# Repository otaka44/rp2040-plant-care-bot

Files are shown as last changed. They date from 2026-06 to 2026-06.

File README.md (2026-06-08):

# 土壌水分センシングロボット（弱いロボット）

RP2040-Zeroを用いた土壌水分センシングロボットのリポジトリです。  
このロボットは、土壌の水分量に応じて表情を変化させることで、人間に対して自然な「助け合い」の動機付けを生み出す「弱いロボット」として設計されています。水分センサーの読み取り、状態に応じた表情制御、およびハードウェア構成に関するソースコードを管理しています。

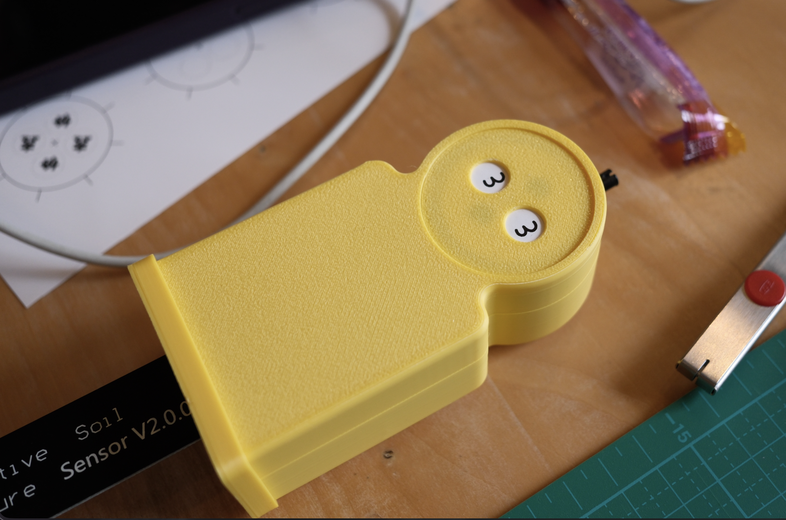
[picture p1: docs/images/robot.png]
完成品


photo by [otaka44](https://github.com/otaka44)

---

## パーツリスト

| パーツ | 型番 | 入手先 | 単価 |
|---|---|---|---|
| マイコン | RP2040-Zero | - | - |
| 静電容量式土壌水分センサー | ノーブランド | - | - |
| サーボモータ | SG90S | [秋月電子 108761](https://akizukidenshi.com/catalog/g/g108761/) | ¥650 |
| ロードスイッチ | TCK108AF | [秋月電子 116073](https://akizukidenshi.com/catalog/g/g116073/) | ¥150 |
| セラミックコンデンサ | 100μF | - | - |
| (*オプション) 圧電スピーカ | PKM13EPYH4000-A0 | [秋月電子 104118](https://akizukidenshi.com/catalog/g/g104118/) | ¥30 |

---

## 回路図

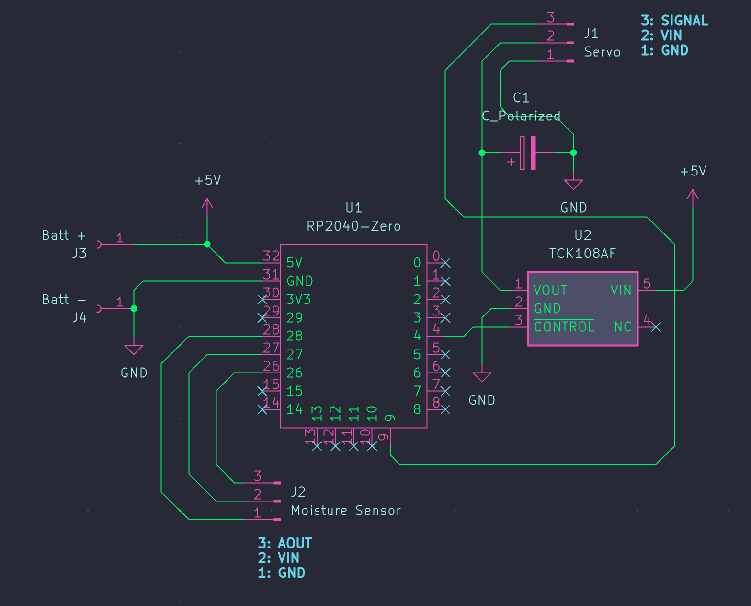
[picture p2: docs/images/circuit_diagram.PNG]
回路図


designed by [Atsuyuki](https://www.instagram.com/aaa_tu)

### 回路の概要

バッテリーから電源を供給し、RP2040-Zeroで水分センサーの値を読み取り、TCK108AF（ロードスイッチ）を介してサーボモーターの電源を制御する構成

| コンポーネント | ピン名称 | 接続先 | 備考 |
| --- | --- | --- | --- |
| **バッテリー (J3)** | 1 (+V) | RP2040-Zero (32ピン: 5V) | 電源供給 |
| **バッテリー (J4)** | 1 (GND) | RP2040-Zero (31ピン: GND) | グランド |
| **RP2040-Zero** | 28ピン | Moisture Sensor (3ピン) | - |
| **RP2040-Zero** | 27ピン | Moisture Sensor (2ピン) | - |
| **RP2040-Zero** | 26ピン | Moisture Sensor (1ピン) | - |
| **RP2040-Zero** | 4ピン | TCK108AF (3ピン: CONTROL) | 電源ON/OFF制御 |
| **TCK108AF** | 1ピン (VOUT) | Servo (1ピン) | サーボ電源出力 |
| **TCK108AF** | 2ピン (GND) | RP2040-Zero (31ピン: GND) | グランド|
| **TCK108AF** | 5ピン (VIN) | +5V (バッテリー側) | 電源供給 |
| **Servo** | 2ピン | RP2040-Zero (9ピン: PWM) | 信号線 |
| **Servo** | 3ピン | RP2040-Zero (31ピン: GND) | グランド |
| **C1 (コンデンサ)** | + | TCK108AF (1ピン: VOUT) | 平滑用 |
| **C1 (コンデンサ)** | - | GND | - |

```mermaid
graph TD
    %% 電源系
    Batt_Plus[Batt + J3] -- +5V --> PowerRail[+5V Rail]
    Batt_Minus[Batt - J4] -- GND --> GNDRail[GND Rail]

    %% マイコン
    subgraph RP2040-Zero [U1: RP2040-Zero]
        P32[Pin 32: 5V]
        P31[Pin 31: GND]
        P28[Pin 28]
        P27[Pin 27]
        P26[Pin 26]
        P9[Pin 4: CONTROL]
        P4[Pin 9: Signal]
    end

    %% スイッチ
    subgraph TCK108AF [U2: TCK108AF]
        U2_1[1: VOUT]
        U2_2[2: GND]
        U2_3[3: CONTROL]
        U2_5[5: VIN]
    end

    %% 周辺機器
    subgraph Moisture_Sensor [J2: Moisture Sensor]
        MS3[3]
        MS2[2]
        MS1[1]
    end

    subgraph Servo [J1: Servo]
        SV1[1: VCC]
        SV2[2: Signal]
        SV3[3: GND]
    end

    subgraph Capacitor [C1]
        C_Pos[+]
        C_Neg[-]
    end

    %% 結線
    PowerRail --> P32
    PowerRail --> U2_5
    GNDRail --> P31
    GNDRail --> U2_2
    GNDRail --> SV3
    GNDRail --> C_Neg

    P28 --- MS3
    P27 --- MS2
    P26 --- MS1

    P9 --> SV2
    U2_1 --> SV1
    U2_1 --> C_Pos
    P4 --> U2_3

    %% スタイル定義
    classDef power fill:#f9f,stroke:#333,stroke-width:2px;
    class PowerRail,GNDRail power;
```

* **RP2040-Zero**: システムの中枢です。
* **水分センサー (Moisture Sensor)**: 26, 27, 28ピンを使用してデータを取得しています。
* **サーボモーター制御**:
* TCK108AFはロードスイッチ（パワーゲート）です。RP2040-Zeroの4ピン（CONTROL）から信号を送ることで、サーボモーターへの電源供給をオンオフする仕組みになっています。サーボモーターのPWM信号はRP2040-Zeroの9ピンから送ります。
* これにより、必要な時だけサーボを動かす省電力設計が可能です。
* **電源**: J3/J4から入力された5VがそのままRP2040-Zeroに供給され、そこから分岐してTCK108AFのVIN（5ピン）に入っています。

---

## ディレクトリ構成

```text
rp2040-zero/
├── README.md
├── docs/
│   └── spec.md
└── src/
    ├── code.py
    └── lib/
        ├── __init__.py
        ├── load_switch.py
        ├── moisture_sensor.py
        ├── piezo_speaker.py
        └── servo_controller.py
```

### ファイルの役割

| パス | 役割 |
| --- | --- |
| `docs/spec.md` | 実装要件の整理 |
| `src/code.py` | Thonny から実行する CircuitPython のメインスクリプト |
| `src/lib/load_switch.py` | TCK108AF の制御ライブラリ |
| `src/lib/moisture_sensor.py` | 水分センサーのアナログ値取得とキャリブレーション |
| `src/lib/servo_controller.py` | PWM によるサーボ角度制御 |
| `src/lib/piezo_speaker.py` | 圧電スピーカーの効果音再生 |

---

## ライブラリ説明

### `load_switch.py`

ロードスイッチ TCK108AF の CONTROL ピンをデジタル出力で制御します。サーボを動かす瞬間だけ電源を供給し、待機中はオフにするために使います。

* `LoadSwitch(pin, active_high=True, initial_on=False)`
* `on()` で電源オン
* `off()` で電源オフ
* `set(on)` で任意状態に設定

### `servo_controller.py`

50Hz PWM を使ってサーボ角度を制御します。角度は 0-180 度の範囲で扱い、内部でパルス幅に変換します。

* `ServoController(pin, min_angle=0, max_angle=180, min_pulse_us=500, max_pulse_us=2400)`
* `set_angle(angle, settle_sec=0.25)` で指定角度へ移動
* `off()` で PWM 出力を停止

### `moisture_sensor.py`

水分センサーのアナログ値を読み取り、電圧値と水分率に変換します。乾燥時と湿潤時の ADC 値を持たせているため、後からキャリブレーション可能です。

* `MoistureSensor(analog_pin, dry_raw=52000, wet_raw=20000, vref=3.3)`
* `read_raw()` で ADC 生値を取得
* `read_voltage()` で電圧値を取得
* `read_percent()` で 0-100% に正規化した水分率を取得
* `set_calibration(dry_raw=None, wet_raw=None)` で校正値を更新

### `piezo_speaker.py`

圧電スピーカーが実装された場合に、状態変化に応じた効果音を鳴らします。未搭載の場合は `src/code.py` で無効化できます。

* `PiezoSpeaker(pin)`
* `tone(frequency_hz, duration_sec=0.1, duty_cycle=32768)`
* `play_dry_effect()`
* `play_wet_effect()`
* `play_humid_effect()`

---

## メインロジック仕様

`src/code.py` は Thonny 上でそのまま実行するメインスクリプトです。一定時間ごとにセンサー値を読み取り、土壌状態を判定し、状態が変わった時だけサーボを動かします。

### 制御フロー

1. 各ライブラリを初期化する
2. 水分センサーの値を一定間隔で読む
3. 水分率から `dry` / `moist` / `wet` を判定する
4. 状態が前回から変化していたらロードスイッチをオンにする
5. サーボを状態に対応した角度へ動かす
6. サーボ移動後にロードスイッチをオフにする
7. スピーカーが有効なら状態に応じた音を鳴らす
8. 次の読み取りまで待機する

### 主な設定変数

| 変数名 | 初期値 | 説明 |
| --- | --- | --- |
| `SERVO_SIGNAL_PIN` | `board.GP9` | サーボ信号線の接続先 |
| `LOAD_SWITCH_PIN` | `board.GP4` | TCK108AF の CONTROL ピン |
| `MOISTURE_ANALOG_PIN` | `board.GP26` | 水分センサーのアナログ入力 |
| `SPEAKER_PIN` | `None` | 圧電スピーカーのピン。未実装時は `None` |
| `DRY_RAW` | `52000` | 乾燥状態として扱う ADC 生値 |
| `WET_RAW` | `20000` | 湿潤状態として扱う ADC 生値 |
| `DRY_THRESHOLD` | `35.0` | 乾燥判定の閾値 [%] |
| `WET_THRESHOLD` | `70.0` | 湿潤判定の閾値 [%] |
| `ANGLE_DRY` | `150` | 乾燥時のサーボ角度 |
| `ANGLE_MOIST` | `90` | 中間状態のサーボ角度 |
| `ANGLE_WET` | `30` | 湿潤時のサーボ角度 |
| `READ_INTERVAL_SEC` | `5.0` | センサー読み取り周期 [秒] |

### 状態判定

* 水分率 `< DRY_THRESHOLD` の場合は `dry`
* 水分率 `>= WET_THRESHOLD` の場合は `wet`
* それ以外は `moist`

### サーボ角度対応

| 状態 | 角度 |
| --- | --- |
| `dry` | `ANGLE_DRY` |
| `moist` | `ANGLE_MOIST` |
| `wet` | `ANGLE_WET` |

### Thonny での運用

* `src/code.py` を `CIRCUITPY/code.py` として配置して実行します
* シェルに `raw=... voltage=... moisture=... state=...` のログが表示されます
* 停止時は Thonny の Shell から `Ctrl+C` を送ります
* キャリブレーション時は `DRY_RAW`, `WET_RAW`, `DRY_THRESHOLD`, `WET_THRESHOLD` を調整します

## 謝辞

本プロジェクトは、watage youth studio「まちの実験室」第3回プログラム —— 「土からはじまる、神田のまちの育て方」にて実施したワークショップ[『土の声をきく、弱いロボットをつくろう』](https://machinojikkennshitsu.peatix.com/view)より生まれました。

本プロジェクトの推進にあたり、ロボットの設計およびデザインは [Atsuyuki](https://www.instagram.com/aaa_tu) 氏を中心とした[otaka44](https://github.com/otaka44)含む関係者一同が担いました。引き続き、拡張パーツの製作ならびに機能拡張に関わるソフトウェアの実装・管理を [otaka44](https://github.com/otaka44)が担当しています。

去る6月7日（日）に開催された本イベントには、多くの方々にご関心をお寄せいただき、無事に実施することができました。会場を提供いただいた watage —Hub for community cultivation— をはじめ、本プロジェクトにご協力いただいたすべての関係者の皆様に、心より御礼申し上げます。

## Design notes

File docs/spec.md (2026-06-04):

## 仕様

- 各パーツを制御するコードを`src/lib/`配下に作成する
- 各パーツリストと回路図は [こちらを参照](../README.md)
- `src/code.py`から各ライブラリを読み込む
- ライブラリは、以下の制御用スクリプトである。
    1. サーボ制御
    2. ロードスイッチ制御
    3. 水分センサーからのアナログ値取得
    4. (オプション)圧電スピーカー制御
- メインロジックは、ある一定時間ごとに土壌水分センサーの値を読み込み、センサーの値によってサーボ角を変化させる。土壌水分センサーの値から土壌が「乾いているか」「湿っているか」の判定閾値は後からキャリブレーションできるようにする。サーボのオンオフはロードスイッチで制御する。オプションとして、後から圧電スピーカーを追加すると、土壌水分センサーの値によるサーボ角変化と合わせて効果音を出すようにすることができる。
- 開発環境は`Thonny`、言語はCircuitPythonを利用する。

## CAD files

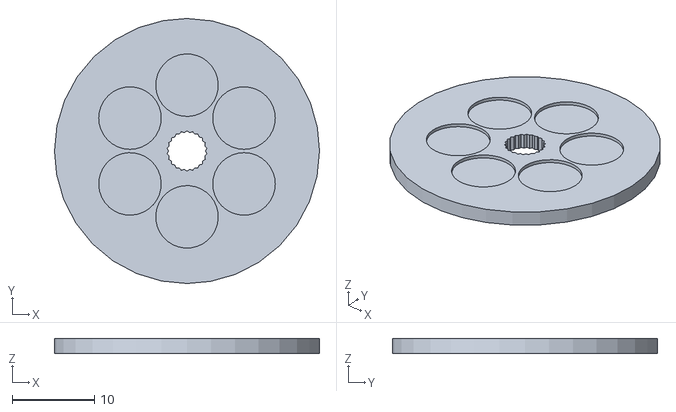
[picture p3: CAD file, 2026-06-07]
case/60deg_face_plate.stl
32.2 x 32.2 x 1.80

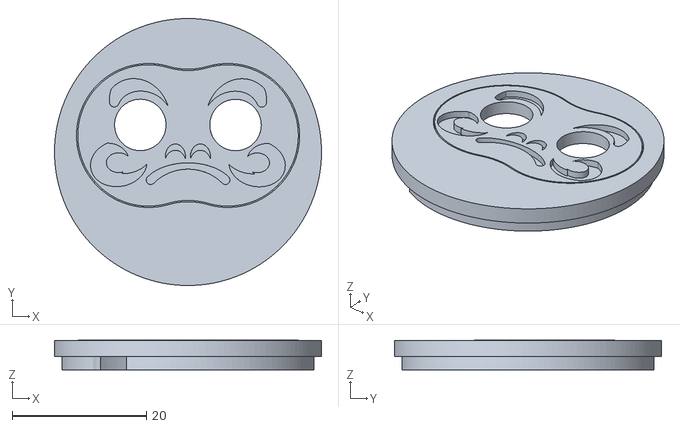
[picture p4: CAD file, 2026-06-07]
case/daruma_fase.stl
39.8 x 39.8 x 4.42

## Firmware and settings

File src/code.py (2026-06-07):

import time

import board

from lib.load_switch import LoadSwitch
from lib.moisture_sensor import MoistureSensor
from lib.piezo_speaker import PiezoSpeaker
from lib.servo_controller import ServoController


# Hardware pin mapping (RP2040-Zero + schematic in README)
SERVO_SIGNAL_PIN = board.GP9
LOAD_SWITCH_PIN = board.GP4
MOISTURE_ANALOG_PIN = board.GP26
MOISTURE_VCC_PIN = board.GP27
MOISTURE_GND_PIN = board.GP28

# Set to None if speaker is not mounted yet.
SPEAKER_PIN = None

# Moisture calibration (adjust later from measured values)
DRY_RAW = 51788
WET_RAW = 25795

# Decision thresholds for soil condition [percent]
DRY_THRESHOLD = 35.0
WET_THRESHOLD = 70.0

# Servo target angles by soil state
ANGLE_DRY = 90
ANGLE_MOIST = 30
ANGLE_WET = 150

# Main loop interval [seconds]
READ_INTERVAL_SEC = 5.0

# Multi-sample stabilization for noisy moisture readings.
MOISTURE_SAMPLE_COUNT = 5
MOISTURE_SAMPLE_INTERVAL_SEC = 0.02


def classify_moisture(percent):
    if percent < DRY_THRESHOLD:
        return "dry"
    if percent >= WET_THRESHOLD:
        return "wet"
    return "moist"


def angle_for_state(state):
    if state == "dry":
        return ANGLE_DRY
    if state == "wet":
        return ANGLE_WET
    return ANGLE_MOIST


def play_effect(speaker, state):
    if speaker is None:
        return
    if state == "dry":
        speaker.play_dry_effect()
    elif state == "wet":
        speaker.play_wet_effect()
    else:
        speaker.play_humid_effect()


def main():
    load_switch = LoadSwitch(LOAD_SWITCH_PIN, active_high=True, initial_on=False)
    servo = ServoController(SERVO_SIGNAL_PIN)
    sensor = MoistureSensor(
        MOISTURE_ANALOG_PIN,
        dry_raw=DRY_RAW,
        wet_raw=WET_RAW,
        vcc_pin=MOISTURE_VCC_PIN,
        gnd_pin=MOISTURE_GND_PIN,
    )
    speaker = PiezoSpeaker(SPEAKER_PIN) if SPEAKER_PIN is not None else None

    previous_state = None
    print("Soil robot start")
    print("Press Ctrl+C in Thonny shell to stop")

    try:
        while True:
            raw = sensor.read_raw_stabilized(
                sample_count=MOISTURE_SAMPLE_COUNT,
                interval_sec=MOISTURE_SAMPLE_INTERVAL_SEC,
            )
            voltage = sensor.raw_to_voltage(raw)
            percent = sensor.raw_to_percent(raw)
            state = classify_moisture(percent)

            print(
                "raw={:5d} voltage={:.3f}V moisture={:5.1f}% state={}".format(
                    raw, voltage, percent, state
                )
            )

            if state != previous_state:
                target_angle = angle_for_state(state)
                # Power servo only when moving for battery saving.
                load_switch.on()
                time.sleep(0.15)
                servo.set_angle(target_angle, settle_sec=0.35)
                load_switch.off()
                play_effect(speaker, state)
                print("servo -> {} deg".format(target_angle))
                previous_state = state

            time.sleep(READ_INTERVAL_SEC)
    except KeyboardInterrupt:
        print("Stopped")
    finally:
        load_switch.off()
        servo.off()
        servo.deinit()
        sensor.deinit()
        if speaker is not None:
            speaker.deinit()
        load_switch.deinit()


main()

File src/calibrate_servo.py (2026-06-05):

import time

import board

from lib.load_switch import LoadSwitch
from lib.servo_controller import ServoController


# Pin mapping (RP2040-Zero)
SERVO_SIGNAL_PIN = board.GP9

# If servo power is switched by a transistor/MOSFET, set to True.
USE_LOAD_SWITCH = True
LOAD_SWITCH_PIN = board.GP4

# Calibration movement settings
START_ANGLE = 90
END_ANGLE = 150
STEP_ANGLE = 60
HOLD_SEC = 2.0


def build_sweep_angles(start_angle, end_angle, step_angle):
    forward = list(range(start_angle, end_angle + 1, step_angle))
    backward = list(range(end_angle - step_angle, start_angle, -step_angle))
    return forward + backward


def main():
    load_switch = None
    if USE_LOAD_SWITCH:
        load_switch = LoadSwitch(LOAD_SWITCH_PIN, active_high=True, initial_on=False)
        load_switch.on()
        time.sleep(0.2)

    servo = ServoController(SERVO_SIGNAL_PIN)
    angles = build_sweep_angles(START_ANGLE, END_ANGLE, STEP_ANGLE)

    print("Servo calibration start")
    print("Move: {} -> {} (step {} deg)".format(START_ANGLE, END_ANGLE, STEP_ANGLE))
    print("Press Ctrl+C in Thonny shell to stop")

    try:
        while True:
            for angle in angles:
                servo.set_angle(angle, settle_sec=0)
                print("servo -> {} deg".format(angle))
                time.sleep(HOLD_SEC)
    except KeyboardInterrupt:
        print("Stopped")
    finally:
        servo.off()
        servo.deinit()
        if load_switch is not None:
            load_switch.off()
            load_switch.deinit()


main()

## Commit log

2026-06-05 センサーとサーボの角度キャリブレーション用スクリプトを追加
2026-06-05 ピン番号の修正
2026-06-05 READMEを更新
2026-06-07 センサー電源制御とセンサー層で複数回サンプリングするよう変更
2026-06-07 顔拡張パーツを追加（だるま）
    [60deg_face_plate.stl, daruma_fase.stl]
2026-06-08 回路図を追加
